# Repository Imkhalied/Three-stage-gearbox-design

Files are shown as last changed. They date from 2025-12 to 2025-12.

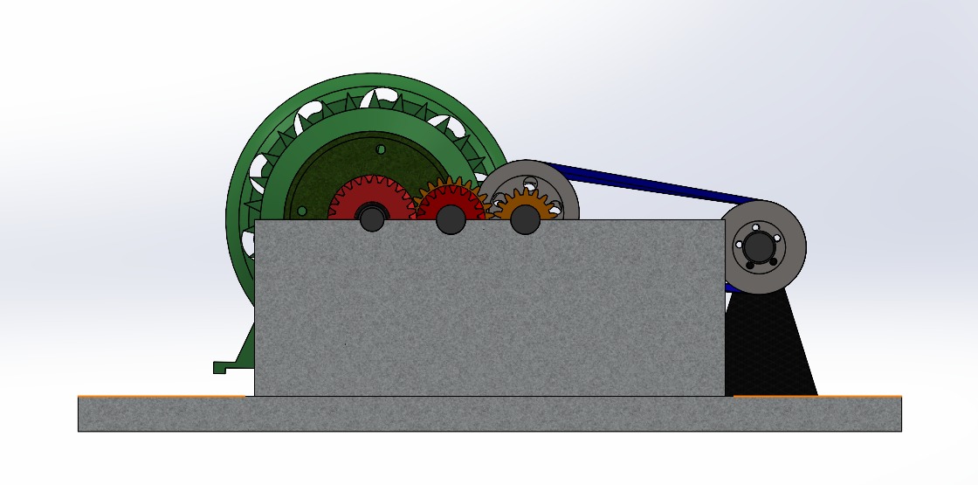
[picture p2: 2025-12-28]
Images/final_assembly_Sideview.jpeg

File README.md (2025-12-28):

# Three-Stage Gearbox Design

## Project Overview
Complete mechanical design of a three-stage gearbox starting from
analytical calculations to full CAD modeling and assembly.

## Project Contents
- Gear ratio and strength calculations
- Shaft,Bearing,Coupling,Gears,Pulley and key design
- Complete CAD parts and assemblies
- Engineering drawings

## Tools Used
- SolidWorks
- Hand Calculations / PDF Documentation

## Supervision
Dr. Mohamed Abdelmotaleb

## Author
Khaled Diaa – Mechatronics Engineering Student

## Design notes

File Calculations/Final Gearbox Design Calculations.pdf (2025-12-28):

1 | P a g e

# MSA

## October University for Modern Science & Arts

## Faculty of Engineering

## Department of Mechatronics Systems Engineering

## Machine Design (MSE243)

# Designing a Speed Increaser Gearbox

### Prepared By

## Khaled Diaa Eldin: 247181

## Joudy Ahmed: 245133

## Ali Abdelelah: 244093

## Seifeldin Eslam: 249437

## Muath Salaheldin: 240019

## Mina Nagy Louis: 248867

## Supervised By

## Dr. Mohamed Abdel Mottaleb

Fall 2025

2 | P a g e

# Table of Contents

# Design Requirements and Specifications

### The project task is to design a 3-stage of step-up gearbox comprised of a

### total of 4 shafts, 2 mating spur gears, 2 mating helical gears, and 2 connected

### belt pulleys. The specific parameters to operate on are:

### ❖ Input Power: 3.5 HP = 2.611 kW

### ❖ Input Speed: 750 rpm

### ❖ Output Speed: 1600 rpm

### ❖ Number of Stages: 3

### ❖ First Stage: Helical Gear

### ❖ Second Stage: Spur Gear

### ❖ Third Stage: Belt

3 | P a g e

# Design Calculations: Gears

## 3.1 Helical Gears

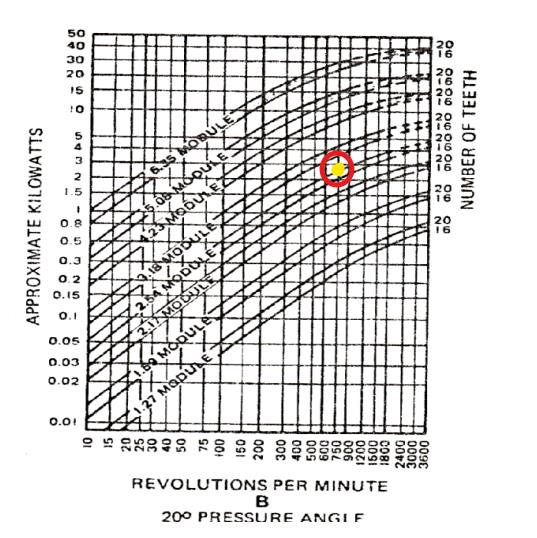
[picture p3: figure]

### ❖ Input Speed: 750 rpm

### ❖ Output Speed: 970 rpm

### ❖ Reduction Ratio: 1.27

### ❖ Pt = π ∗ m =8.63

### ❖ Pressure angle α = assume 20

❖ Px =

Pt
tan α

### = (8.63/tan 20) = 23.71

### ❖ F = 2Px m ≈ 59.275 mm

### ❖ Fa = wt

### tan β

### ❖ Helix angle β =assume 20

### ❖ N1 = 18 teeth

### ❖ m=2.54→Choose2.75(Next

### choice)

### ❖ d1 = N1*m = 18*2.75 = 49.5 mm

### ❖ N2 = N1*RR = 18*1.29≈24 teeth

### ❖ d2 = N2*m = 24*2.75 = 66 mm

## Safety Checks:

### 1. Bending Stress:

wt =

Power
Velocity =

2611
(

π∗D∗N
60

)

=

2611
(

π∗0.0495∗750
60

)

= 1340 N

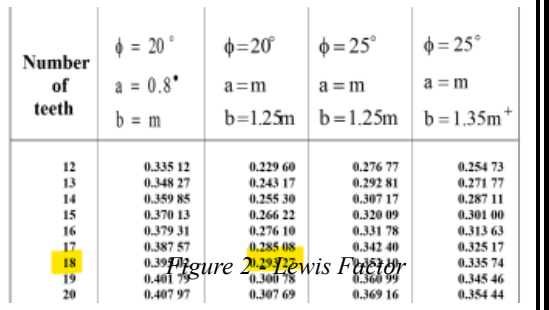
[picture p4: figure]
Figure 2 - Lewis Factor

Kv =

6
6 + V

= 0.7556 , Y = 0.29327

σ =

wt
F ∗ Kv ∗ m ∗ Y

Figure 1 - Module Table

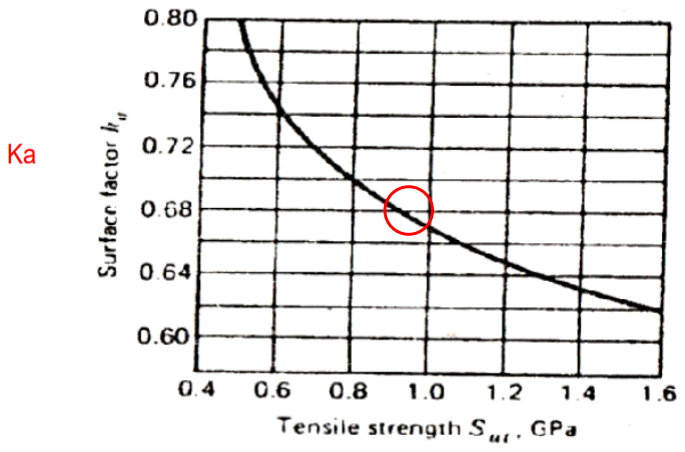
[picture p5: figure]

4 | P a g e

σ =

1340
0.059.275 ∗ 0.7556 ∗ 2.75 ∗ 0.29327 = 37.097MPa

σdesign = F. S ∗ σ = 2 ∗ 37.097 = 74.19 MPa

Cℎoose 1095 As rolled ; σy = 572.3 MPa , HB = 293

### 2. Bending Fatigue:

### Se = Ka KbKcKdKeKfSe

′

Figure 3 - Ka Table

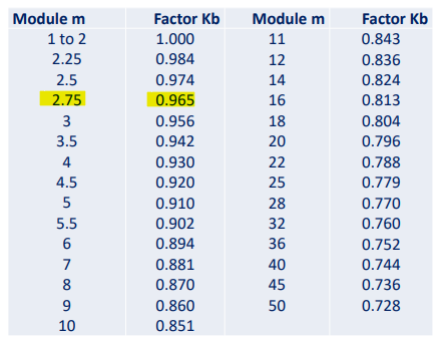
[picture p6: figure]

Figure 4 - Kb Table

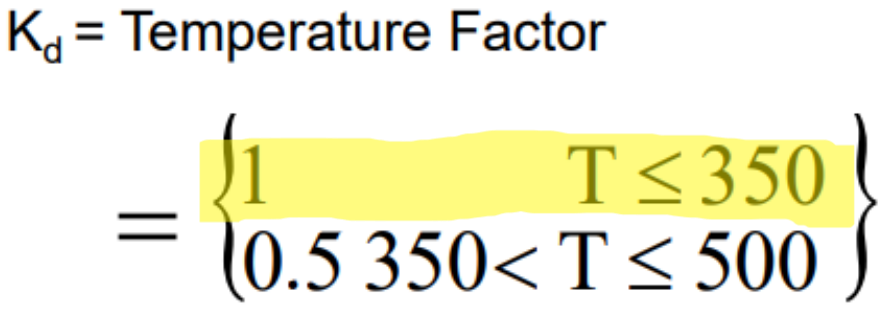
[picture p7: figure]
Figure 5 - Kc Table

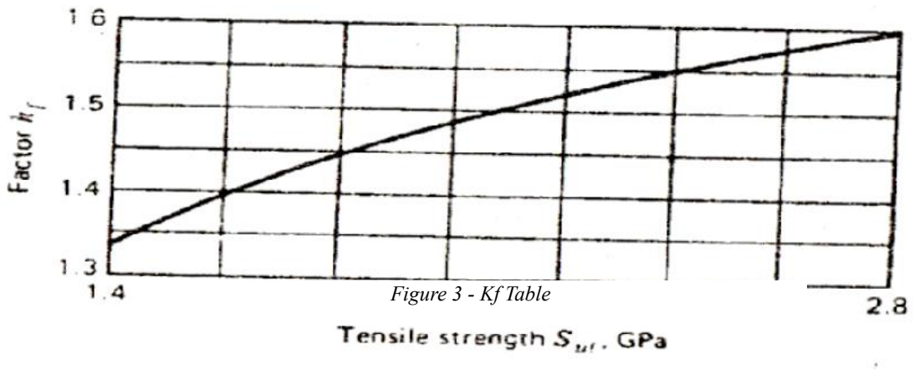
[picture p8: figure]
Figure 3 - Kf Table

5 | P a g e

## Ke = Modified factor for stress concentration = 1

Ka = 0.68

Kb = 0.956

Kc = 0.725

Kd = 1

Ke = 1

Kf = 1

Se

′ =

σult
2

=

955.3
2

### = 482.65MPa

### Se = 229.61MPa

σa =

1340
0.059 ∗ 0.7556 ∗ 2.75 ∗ 0.33214 = 32.755MPa

nG =

Se
σa

=

2291.61
32.755 = 7

n =

nG
KoKm

=

7
1 ∗ 1.3

= 4.3 > 1

## Safe

Figure 4 - Geometry Factor

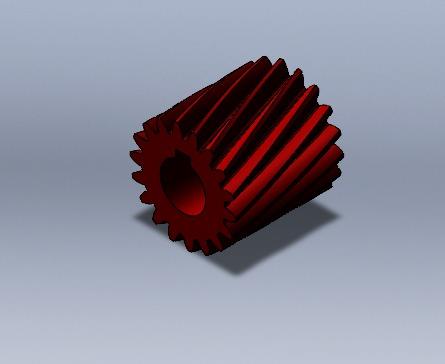
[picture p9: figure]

6 | P a g e

### 3. Surface Durability:

### Sc = 2.76 ∗ HB − 70 = 2.76 ∗ 293 − 70 = 738.68 MPa

SH =

### CLCH CTCR

∗ Sc =

1 ∗ 1
1 ∗ 1.25

### ∗ 738.68 = 590.944 MPa

### σH = 590.944 MPa = Cp√

wtp

### Cv ∗ F ∗ d ∗ I

I =

### cos ∅ sin ∅

2

∗

m
m + 1

= 0.1178

σH = 191√

wtp
0.7556 ∗ 0.059 ∗ 0.0495 ∗ 0.1178

### wtp = 2492 N

nG =

wtp
wt

=

2492
1340 = 1.86

n =

nG

### cocm

=

1.86
1 ∗ 1.3

= 1.14 > 1

## Safe

Figure 7 - Driven Helical Gear Figure 6 - Pinion Helical Gear

7 | P a g e

## 3.2 Spur Gears

### ❖ Input Speed: 750 rpm ❖ Output Speed: 970 rpm ❖ Reduction Ratio: 1.3 ❖ N1 = 18 teeth

❖ m = 2.75

### ❖ d1 = N1*m = 18*2.75 = 49.5 mm ❖ N2 = N1*RR = 18*1.3≈ 24 teeth ❖ d2 = N2*m = 24*2.75 = 66 mm

### ❖ F = 4 ∗ π ∗ m = 34.55mm ≈ 35mm

## Safety Checks:

1- Bending Stress:

wt =

### Power Velocity =

2611
(

π∗D∗N
60

)

=

2611
(

π∗0.0495∗970
60

)

= 1028 N

Kv =

6
6 + V

= 0.7 , Y = 0.29327

σ =

wt

### F ∗ Kv ∗ m ∗ Y

=

1038.55

### 0.035 ∗ 0.7 ∗ 2.75 ∗ 0.29327 = 52 MPa

### σdesign = F. S ∗ σ = 2 ∗ 52 = 104 MPa < σy

## Safe

8 | P a g e

2- Bending Fatigue

### Se = Ka KbKcKdKeKfSe

′

Ka = 0.8

Kb = 0.965

Kc = 0.725

Kd = 1

Ke = 1

Kf = 1

Se

′ =

σult
2

=

424
2

### = 212 MPa

### Se = 118.65 MPa

σa =

wt

### F ∗ Kv ∗ m ∗ J

=

1038.55

### 0.035 ∗ 0.88 ∗ 2.75 ∗ 0.33814 = 36.54 MPa

nG =

Se
σa

=

118.65
36.54 = 3.255

n =

nG

### KoKm

=

3.255
1 ∗ 1.3

= 2.5 > 1

## Safe

9 | P a g e

3- Surface Durability:

### Sc = 263.96 MPa

SH =

### CLCH CTCR

∗ Sc =

1 ∗ 1
1 ∗ 1.3

### ∗ 263.96 = 343.148 MPa

### σH = Cp√

wt

### Cv ∗ F ∗ d ∗ I

;I =

### cos ∅ sin ∅

2

∗

m
m + 1

= 0.1175

σH = 191√
584

### 0.88 ∗ 0.035 ∗ 0.05 ∗ 0.1175 = 343.148 MPa

nG =

SH
σH

=

584
1038 = 0.568

n =

nG

### cocm

=

0.568
1 ∗ 1.3

= 0.437 > 1

## Not Safe

Cℎanged material to 1050 Normalized ;

HB = 201

### Sc = 484.76 MPa

SH =

### CLCH CTCR

∗ Sc =

1 ∗ 1
1 ∗ 1.3

### ∗ 484.76 = 630.18 MPa

### wtp = 1.915 N

n =

nG

### cocm

=

1.915
1 ∗ 1.3

= 1.473 > 1

## Safe

10 | P a g e

Figure 6 - Pinion Spur Gear

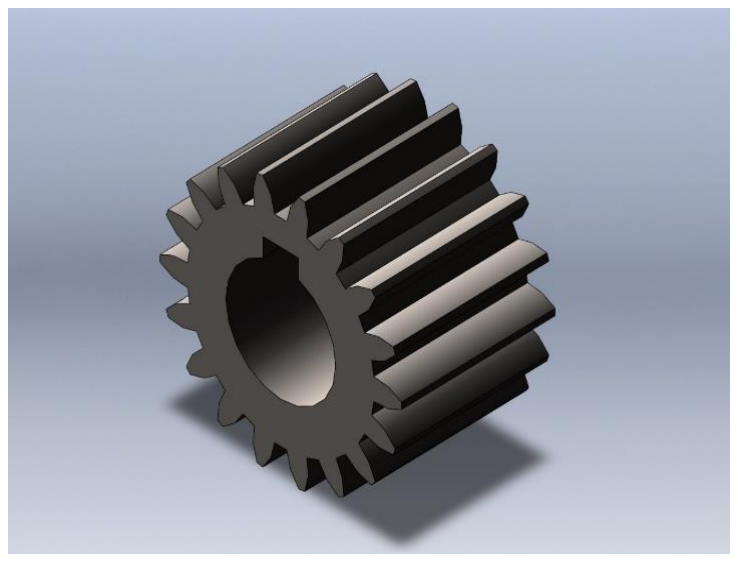
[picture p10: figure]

Figure 5 - Driven Spur Gear

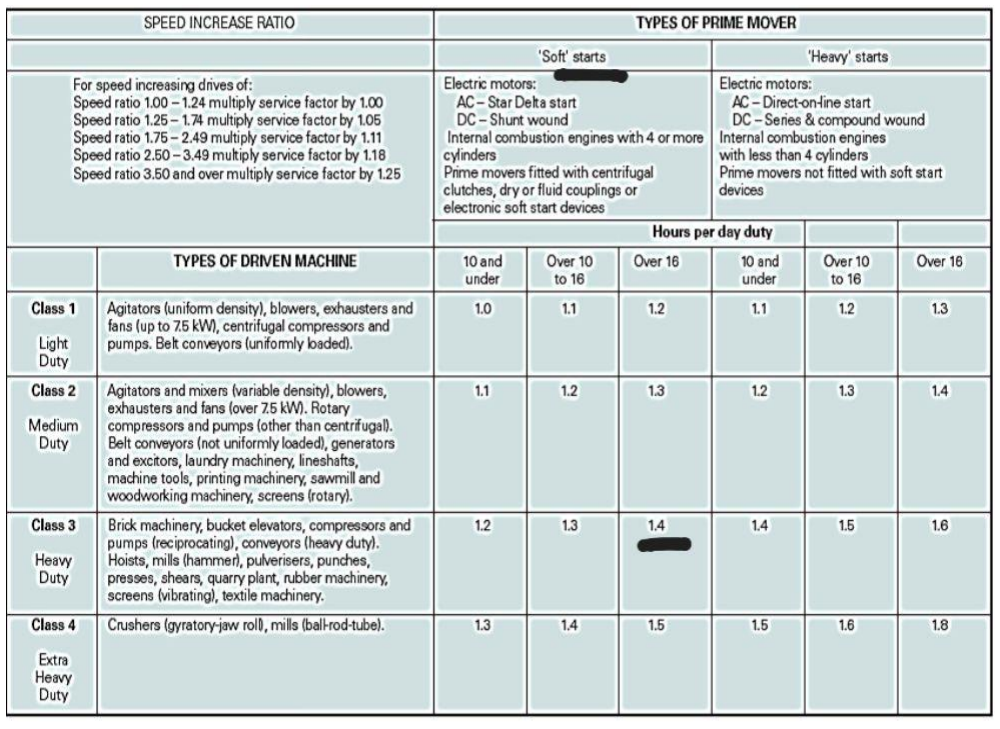
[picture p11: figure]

11 | P a g e

# Pulley and Belt Design

### Input Power= 3.5 Hp = 2.611 KW

### ❖ Input Speed = 1260 rpm

### ❖ Reduction ratio= 1.27

(a) Speed Ratio

Speed ratio=0.02

(b) Service Factor

From Table 3 the service factor is 1.4 .as we use an internal combustion engine with 4

cylinders

➔ Class 2→ Agitators and Mixers → (over 16) hours

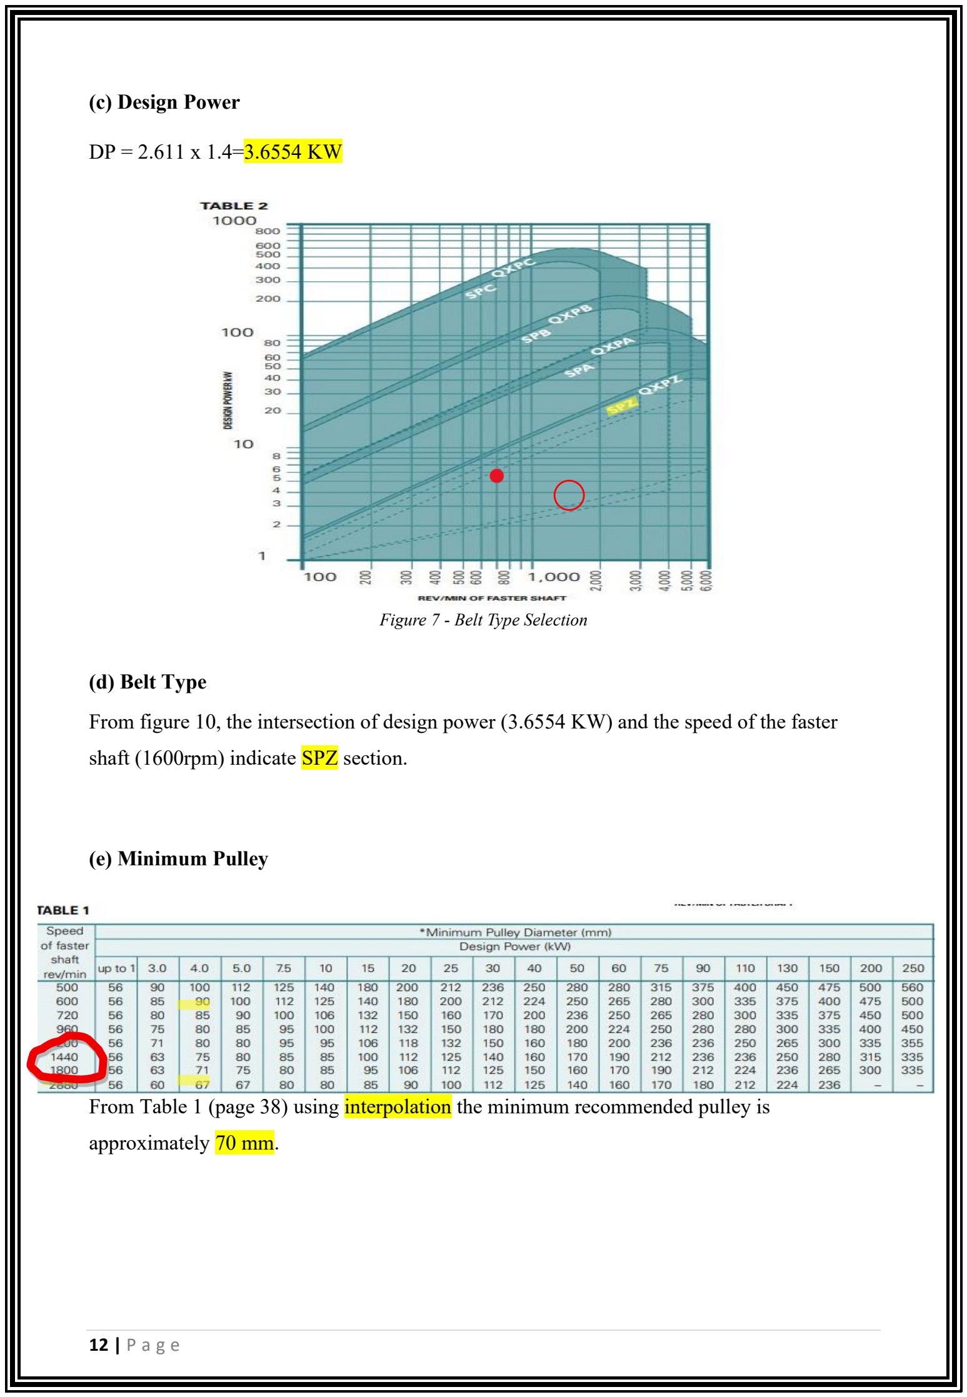
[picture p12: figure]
(c) Design Power; (d) Belt Type; shaft (1600rpm) indicate SPZ section.; (e) Minimum Pulley; approximately 70 mm.; Figure 7 - Belt Type Selection

From figure 10, the intersection of design power (3.6554 KW) and the speed of the faster

From Table 1 (page 38) using interpolation the minimum recommended pulley is

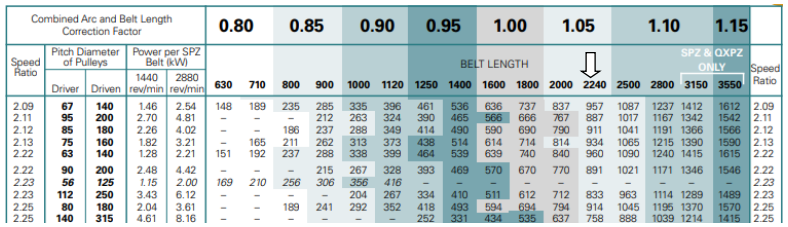
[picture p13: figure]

13 | P a g e
(f) Pulley Pitch Diameters

By referring to the center distance tables relating to SPZ section belts on page 47 at reduction

ratio 1.293, the selection is a driving pulley of 70 mm pitch diameter and a driven pulley of

71 mm and 90 mm pitch diameter.

(g) Belt Length, Centre Distance and Correction Factor

Reading across the table, the nearest center distance to the 873 mm required is 994 mm. The

belt length at the head of the column is 2240 mm. By following the shading of the color to the

top of the table, a correction factor of 1.05 is noted.

(h)Rated Power per Belt

From the power rating table (pages 54 & 57), the rated power is 1.57kW(Using interpolation)

for Power Plus SPZ(power per belt).

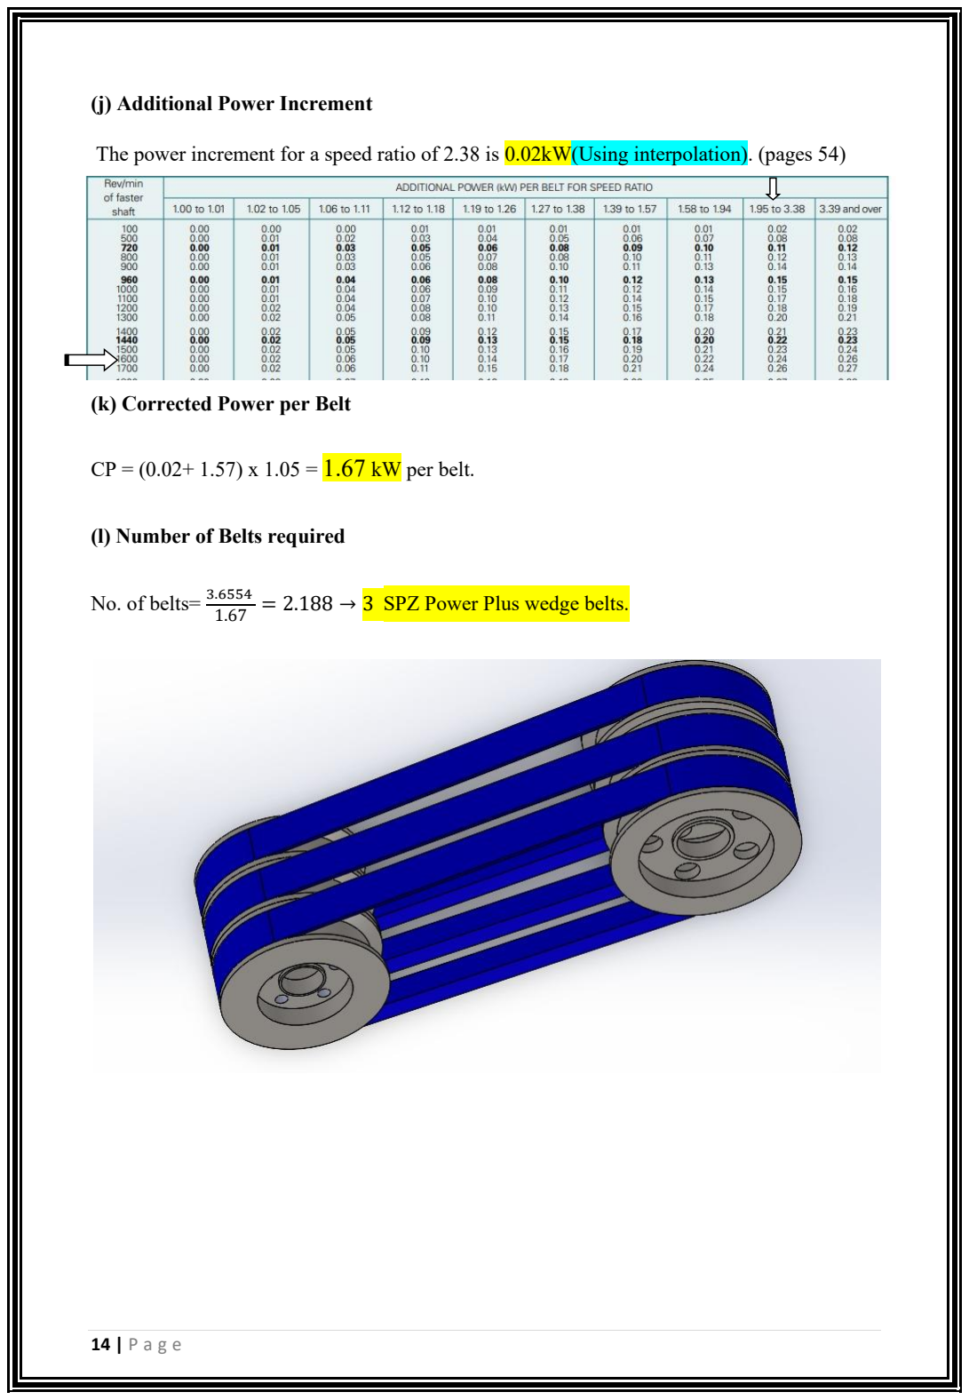
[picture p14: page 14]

14 | P a g e
(j) Additional Power Increment

The power increment for a speed ratio of 2.38 is 0.02kW(Using interpolation). (pages 54)

(k) Corrected Power per Belt

CP = (0.02+ 1.57) x 1.05 = 1.67 kW per belt.

(l) Number of Belts required

No. of belts=

3.6554
1.67 = 2.188 → 3 SPZ Power Plus wedge belts.

15 | P a g e

### Therefore, the results of the belt design are the following:

### ❖ Input Speed: 1260 rpm

### ❖ Output Speed: 1600 rpm

### ❖ Reduction Ratio: 1.27

### ❖ Power: 2611 W

### ❖ Service Factor = 1.4

### ❖ Design Power =

2.611*1.4= 3.6554 kW

### ❖ Belt Type: SPZ

### ❖ Minimum Pulley

### Diameter = 70 mm

### ❖ Pulley Diameters = 71 &90 mm

### ❖ Center Distance = 873-994 mm

### ❖ Belt Length = 2000-2240 mm

### ❖ Correction Factor = 1.05

### ❖ Rated Power = 1.57 kW

### ❖ Additional Power

### Increment = 0.02 kW per belt

### ❖ Power Per Belt =

1.05(1.57+0.02) =

### 1.67 kW/belt

### Number of Belts =

### Design Power Power Per Belt =

3.6554

### 1.67 = 2.188 ≈ 3 belts

16 | P a g e

# Coupling Design

1. Input Power= 3.5 HP
2. Input Speed = 750 rpm

1- Select a type of coupling

Choose a cast iron rigid coupling→ Cast iron

2- Selecting a proper material with a yield strength from the table material

From table of (AISI) 1030 asrolled with yield strength (σ yield)344.7 MPa, Factor of safety= 6

Permissible shear stress for bolts, shaft, and key material: 0.5 SY
F.S

=

0.5∗344.7
6

=28.725MPa

Crushing stress for bolt and key material:
SY
F.S

=

344.7
6

=57.45 MPa

Permissible shear stress for cast iron: 8 MPa(assume )

3- Get Torque from power

Power= 3.5Hp = 2611 W = 2.611 KW

Power= Tw

T= input Power
input speed

=

P
2πN
60

=

2.611∗ 10³
2π∗750
60

= 33.25 N.m

17 | P a g e

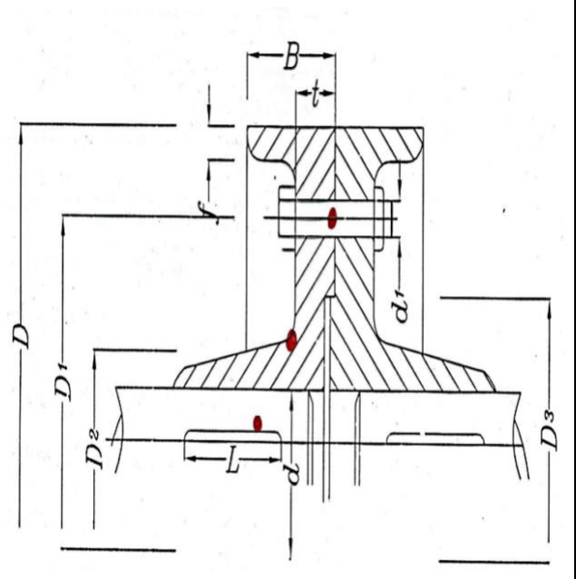
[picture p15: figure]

5- Coupling dimensions proportions (see Figure) for

the nomenclature

1. No. of bolts =n = 0.02d+3= 0.02*20+3= 3.4≈

4 bolts (even number for symmetry)

2. d1(diameter of bolts)=

0.5d
√n

=

0.5∗20
√4

=5mm ≈M6

3. D1(diameter of pitch circle)= 4d = 4*20=80mm
4. D2(outer diameter of hub) = 2d= 2*20=40 mm
5. L1(length of hub) = 1.5d= 1.5*20= 30 mm
6. D(outside diameter of flange)= 5d= 5*20= 100 mm

(Diameter of Coupling)

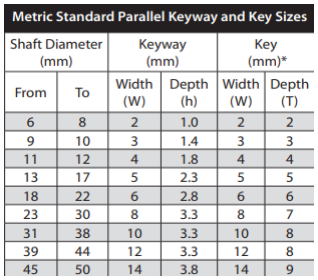
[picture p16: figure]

7. t= 1.2 d1= 1.2*6=7.2mm
8. f= 6 for Cast Iron

From table of Metric standard keyway and key size at

d= 20 mm

Keyway: W= 6mm, h= 2.8 mm

Key: W= 6 mm, h= 6 mm

6- the following checks should be doneafter the assumptions of the coupling dimensions

1- Direct shear check on bolts:

Fbolt =

2T
nD1

=

2∗33,25
4∗80∗10⁻³ = 207,8 N

τbolt =

F
π
4

d1

2 =

207,8
π
4

∗6

2 = 7,36 MPa <28.7 MPa

∴ It’s SAFE

2- Bearing pressure on bolts:

σb =

Fb
d1∗t

=

207.8
6∗7.2

= 4.81 MPa

σb =

Sb
F. S

→ 4.81 <

57.45x10⁶
6

= 9.575 MPa

18 | P a g e

∴ It’s SAFE

3- Shear of the flange at hub:

τ =

2T
πD2

2
∗t

=

2∗33.25
π∗40²∗7.2

= 1.84 MPa< 8 MPa

∴ It’s SAFE

4-Shear Stresson Key

τkey =

2T
d∗w∗L

=

2∗33,25
20∗6∗30

= 18,4 MPa < 28,725 MPa

∴ It’s SAFE

36.9 MPa < 57.45 MPa

∴ It’s SAFE

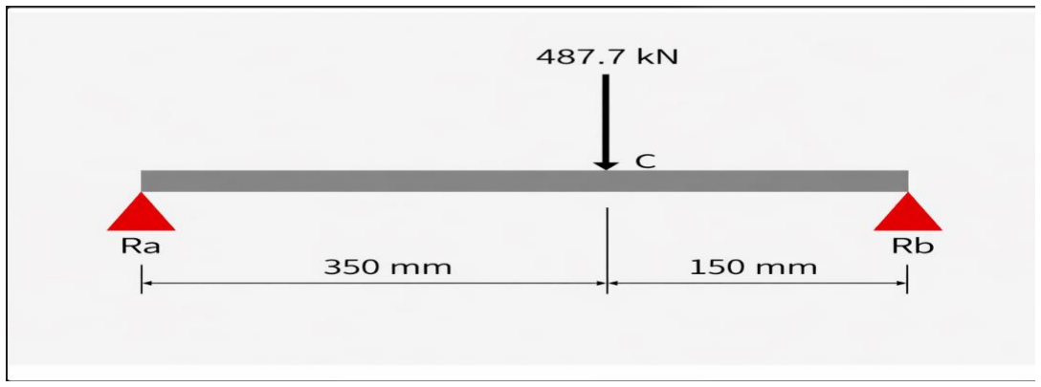
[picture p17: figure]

19 | P a g e

# Shafts Design

1

## st Shaft: (Helical)

Power = 2.611 kW

(X-Y Plane)

### ❖ Tangent force wt= 1340 N

### ❖ Axial force Fa = wt

### tan β= 487.7 N

### ❖ Normal force FN = wt

### tan α = 487.7 N

### ❖ RA=146.31 N ❖ RB=341.4 N

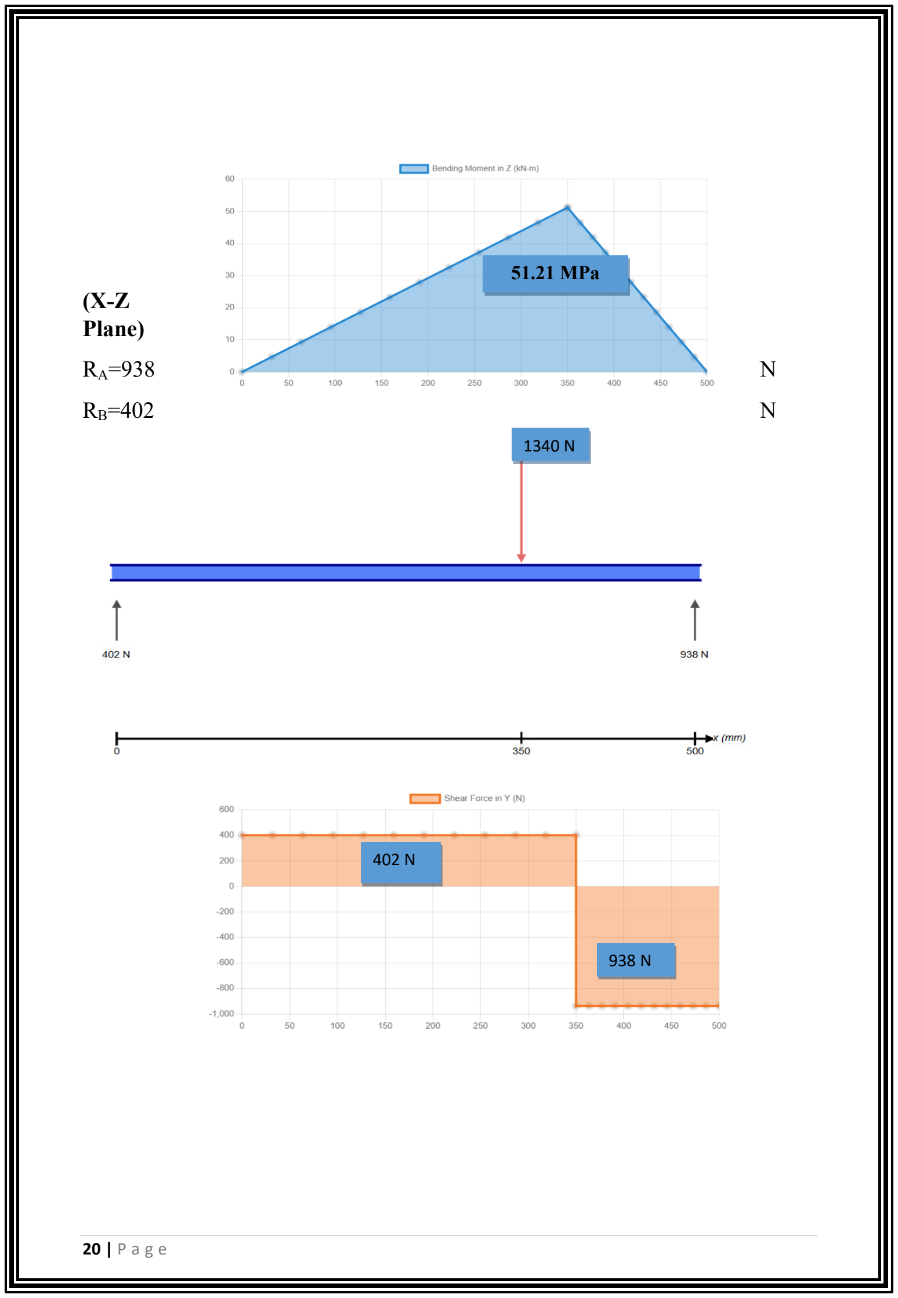
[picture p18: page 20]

20 | P a g e

(X-Z
Plane)
RA=938 | N
RB=402 | N

### 51.21 MPa

1340 N

402 N

938 N

21 | P a g e

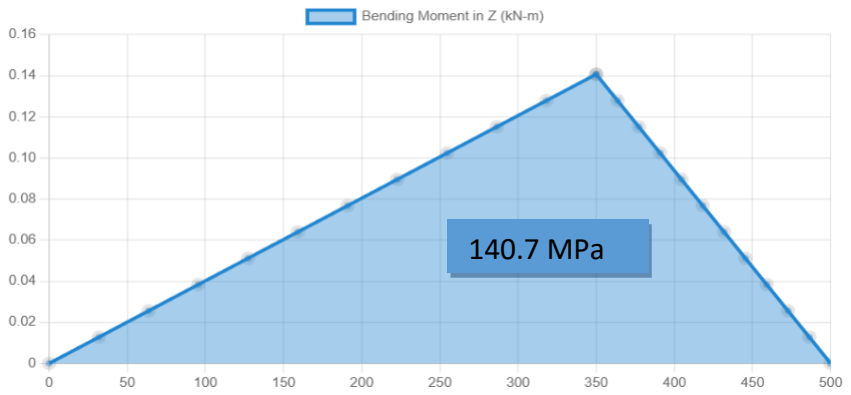
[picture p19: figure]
140.7 MPa

### Momentmax = √140.7 2 + 51.21² + 12.071² = 150.21 Nm

### Torquemax= 33.24Nm

### Km = Kt = 1.5

d

3 =

32 ∗ FS

### π ∗ Sy

### ∗ √(Kt ∗ Torquemax) 2 + (Km ∗ Momentmax)

2

### d = 18.3mm→ Choose 20mm

## 2nd Shaft: (Spur + Helical)

22 | P a g e

Power =2.611 kW

(X-Y Plane)

### RA=78.181 N

### RB=191.72 N

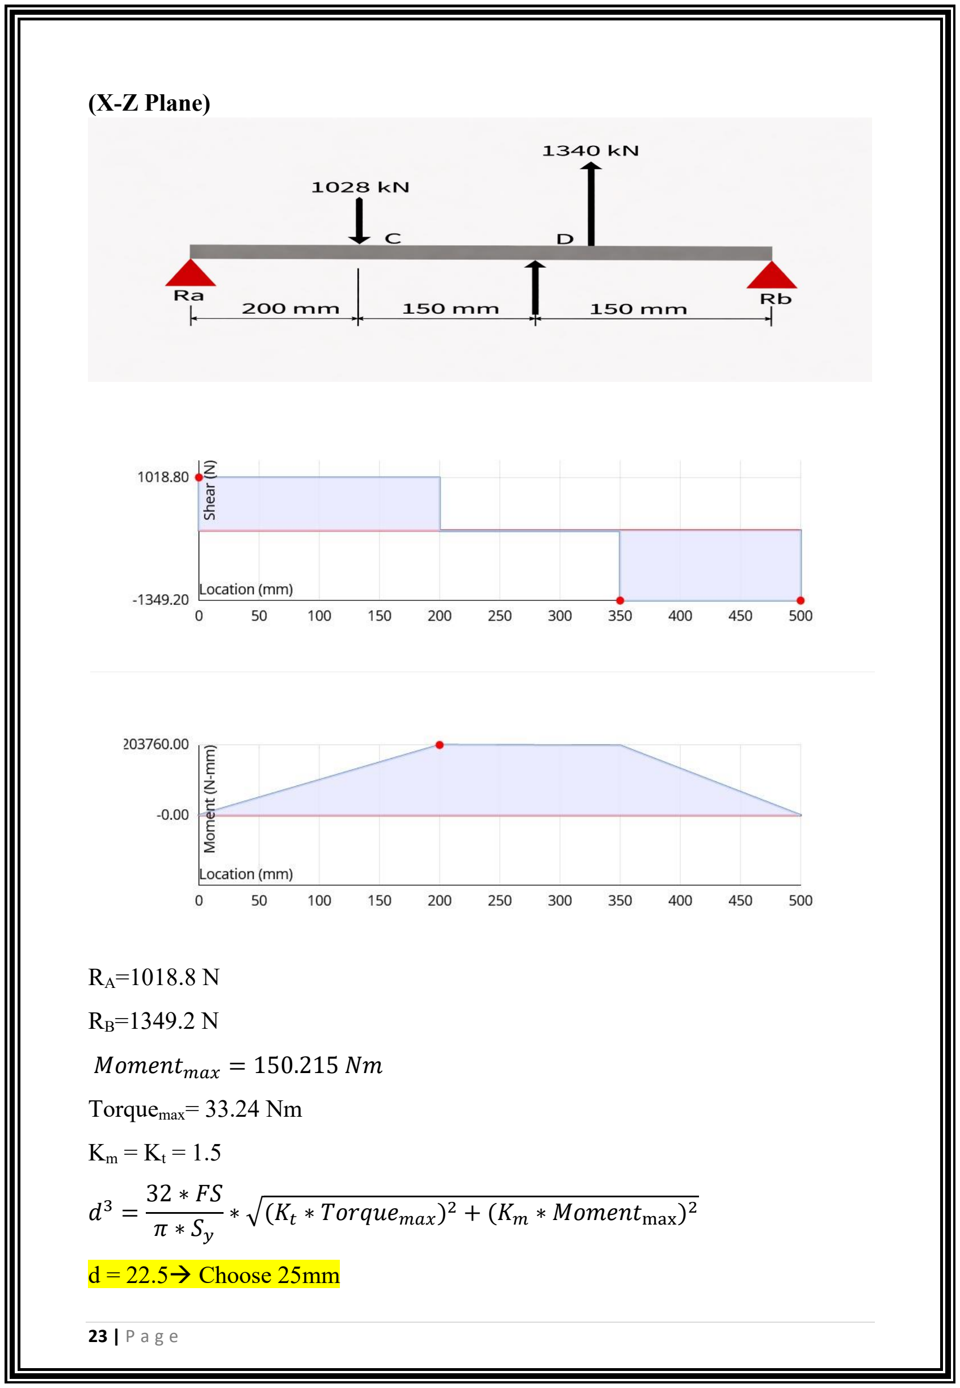
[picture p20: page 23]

23 | P a g e

(X-Z Plane)

### RA=1018.8 N

### RB=1349.2 N

### Momentmax = 150.215 Nm

### Torquemax= 33.24 Nm

### Km = Kt = 1.5

d

3 =

32 ∗ FS

### π ∗ Sy

### ∗ √(Kt ∗ Torquemax) 2 + (Km ∗ Momentmax)

2

### d = 22.5→ Choose 25mm

24 | P a g e

## 3rd Shaft: (Helical + Belt Pulley)

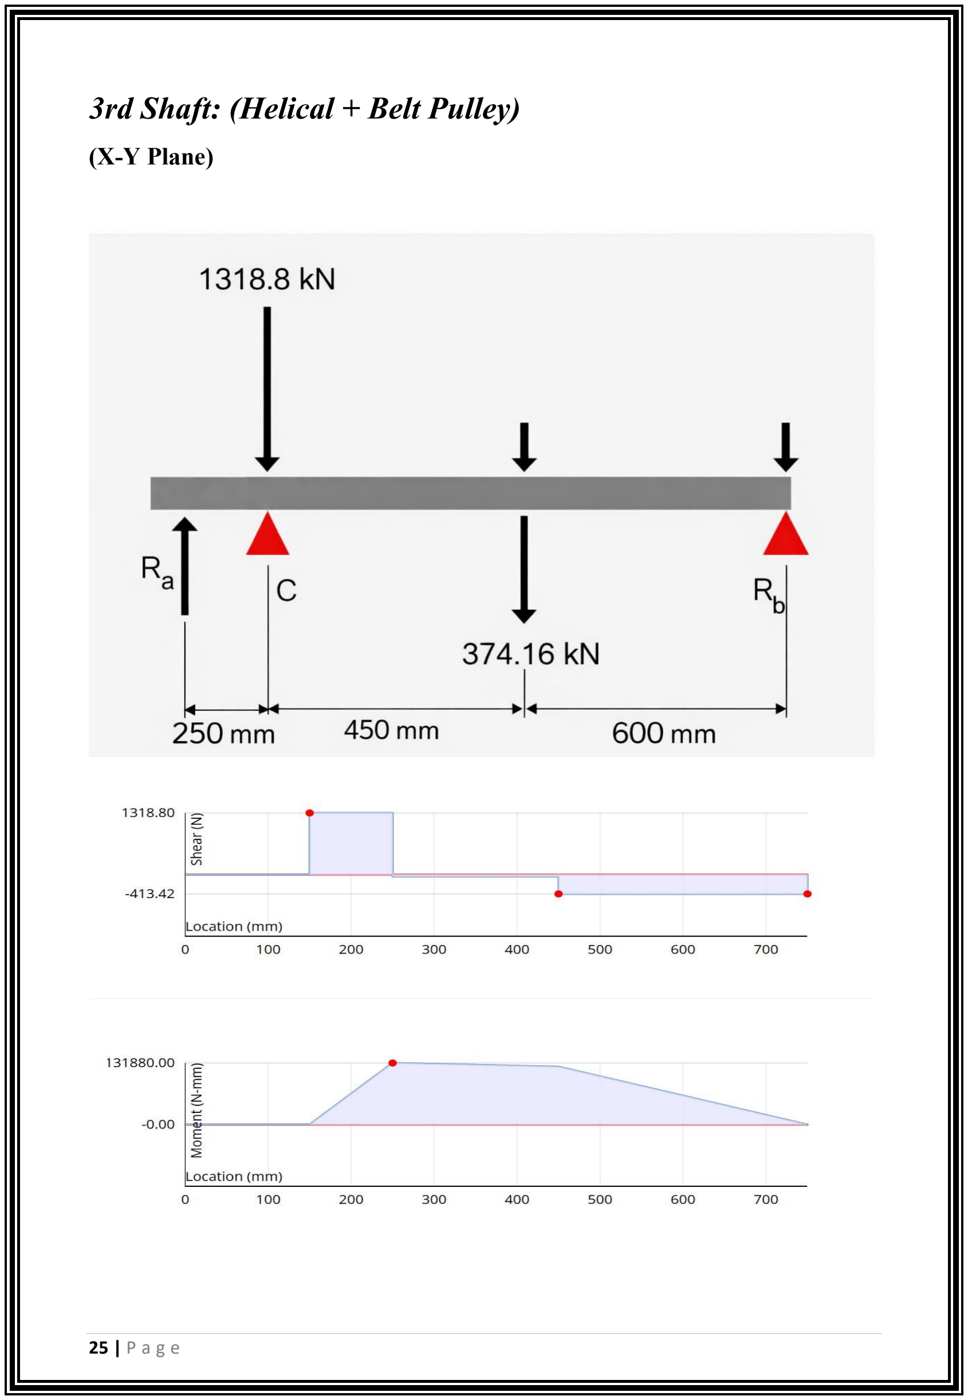
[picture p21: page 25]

25 | P a g e

(X-Y Plane)

26 | P a g e

### RA=1358.064 N

### RB=413.405 N

(X-Z Plane)

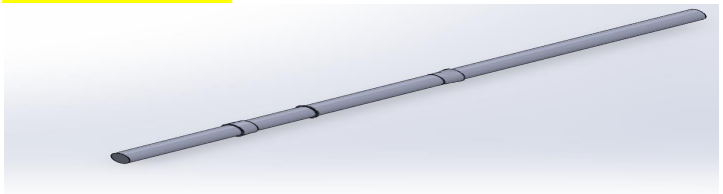
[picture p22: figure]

27 | P a g e

### RA=616.8 N

### RB=411.2 N

### Momentmax = 180.58 Nm

### Torquemax= 19.78 Nm

### Km = Kt = 1.5

d

3 =

32 ∗ FS

### π ∗ Sy

### ∗ √(Kt ∗ Torquemax) 2 + (Km ∗ Momentmax)

2

### d = 21.5→ Choose 25mm

## 4th Shaft: (Belt Pulley)

28 | P a g e

(X-Y Plane)

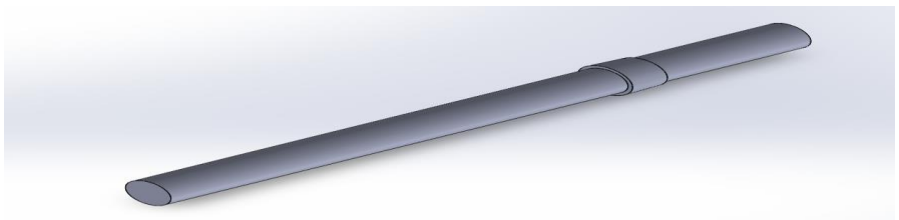
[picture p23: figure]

29 | P a g e

### RA=955.17 N

### RB=716.378 N

### Momentmax = 143,27 Nm

### Torquemax= 1671.549 Nm

### Km = Kt = 1.5

d

3 =

32 ∗ FS

### π ∗ Sy

### ∗ √(Kt ∗ Torquemax) 2 + (Km ∗ Momentmax)

2

### d = 20→ Choose 25mm

30 | P a g e

# Bearings Design

1

## st Shaft:

Choose ball bearing

1- Select bearing type from the data sheet table, then get C, Co

At diameter 20 mm

RPm = 750

Fr = 998.95 KN

Fa = 773.65 KN

From table bearing type: Single row deep groove ball bearings61804-2RS1

C= 4.03 kN, Co= 2.32 kN

ΣFy ∣B= √(341.4)
2 + (938)

2 = 998.095 N
FR = 998.95 N
Fa = FRtan (20∘

) = 1340tan (20∘
) = 773.65 N

2- Get P

⸪P = 0.56Fr + yFa | @ y =

0.44
e

⸫e = 0.5 (

Fa
Co

)

0.225
= 0.39

⸪ IfFa
Fr

≤ e then P = Fr

If Fa
Fr

≥ e then P = 0.56Fr + yFa

31 | P a g e

⸫

Fa
Fr

≥ e

0.774 ≥ 0.39

⸪P = 0.56 ⋅ 998.95 + y ⋅ 773.652 @ y =

0.44
e

= 1.128

P = 1432.294 N

3-Assume life, for gear box L=12,000 working hr

4- Calculate L=

[

C
P

]

a
X106

N 60

to get C where a=3 (ball bearing)

L=

[

C
P

]

a
X10⁶

N∗ 60

; 12,000=

[

C
1432.294 ]

3
X10⁶

∗ 60
From equation above, get C = 11.663 kN>4.03 kN

IT’S NOT SAFE

⸫ Change material to 6204

C = 13.55 kNCo = 6.55 kN

⸪e = 1.463y =

0.44
e

= 0.3

- P = Fr = 998.65 N

•

[

C
P

]

a
X106

N 60

C` = 8. 132 kN

- C`<C 8.132<13.55

⸫ IT`S SAFE

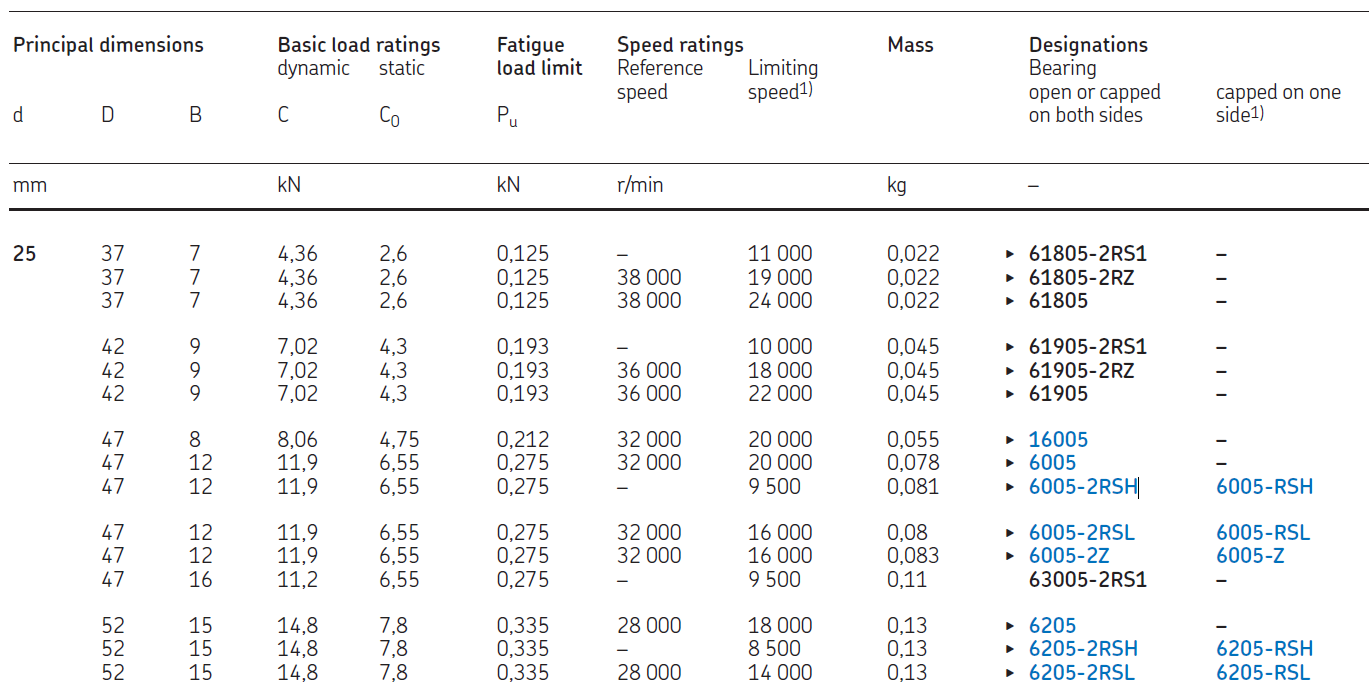
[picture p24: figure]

32 | P a g e

2

## ndShaft:

Given data:

dsℎaft = 25 mm

N = 970 rpm

Fa = 773,65 N

Fr = 1362 N

Choose ball bearing

1- Select bearing type from the data sheet table, then get C, Co

At diameter 25 mm

From table bearing type: 6205-2RSH

C= 14.8kN, Co= 7.8 kN

FR ∣B= √(1352.2)
2 + (191.78)

2 = 1362 N
Fa = FRtan (30∘
)
Fa = 1340tan (30∘
) = 773.65 N

2-Assume life, for gear box L=12,000 working hr

33 | P a g e

3-Get P

e = 0.5(

Fa
Co

)

0.225 = 0.5(

773,65
7800 )

0.225 = 0.2973

Fa
Fr

=

773,65
1362 = 0.568; > e,tℎen P = 0.56Fr + (

0.44
e

)Fa

P = 0.56 ∗ 1362 + (

0.44
0.2973) ∗ 773,65 = 1907.722 N

4- Calculate L=

[

C
P

]

a
X106

N∗ 60

to get C where a=3 (ball bearing)

L=

[

C
P

]

a
X10⁶

N ∗ 60

= 12,000=

[

C`
1907.722]

3
X10⁶

970∗ 60

From the equation above, get C`= 16.925 kN>14.8 kN

IT’S NOT SAFE

- Changing material to 6305 ETN9

C= 26 kN Co = 13.4 kN
e=0.2632 y =

0.44
e

= 1.6717

•p = 0.56 ∗ 1362 + 1.6717 ∗ 773.65= 2056.03 N

- C`=18.241 kN

⸫ C`< C

18.241<26

IT’S SAFE

34 | P a g e

3

## rdShaft:

Given data:

dsℎaft = 25mm

N = 1260 rpm

Fa = 0

Fr = 1491.51N

17.8 9.3

Choose ball bearing

1- Select bearing type from the data sheet table, then get C, Co

At 25 mm diameter

From table bearing type: Single row deep groove ball bearings6205 ETN9

C= 17.8 kN, Co= 9.3 kN

35 | P a g e

2-Assume life, for gear box L=12,000 working hr

3-Get P

P = Fr = 1491.5 N

4- Calculate L=

[

C
P

]

a
X106

N 60

to get C where a=3 (ball bearing)

L=

[

C
P

]

a
X10⁶

N∗ 60

= 12,000=

[

C`
1491.51]

3
X10⁶

1260∗ 60
From the equation above, get C`= 14.438kN<17.8 kN

IT’S SAFE

36 | P a g e

4

## thShaft:

Given data:

dsℎaft = 25 mm

N = 1600

Fa = 0

Fr = 955.17N

Choose ball bearing

1- Select bearing type from the data sheet table, then get C, Co

At 25 mm diameter

From table bearing type: Single row deep groove ball bearings6005-2RSH

C= 11.9 kN, Co= 6.55 kN

2-Assume life, for gear box L=12,000 working hr

3-Get P

⸪ Fa = 0

⸫ P=Fr= 955.17 N

4- Calculate L=

[

C
P

]

a
X106

N 60

to get C where a=3 (ball bearing)

L=

[

C
P

]

a
X10⁶

N 60

= 12,000=

[

C`
955.17]

3
X10⁶

300 ∗ 60
From the equation above, get C`= 10.013 kN<11.9 kN

IT’S SAFE

# Assembly Drawings (SolidWorks)

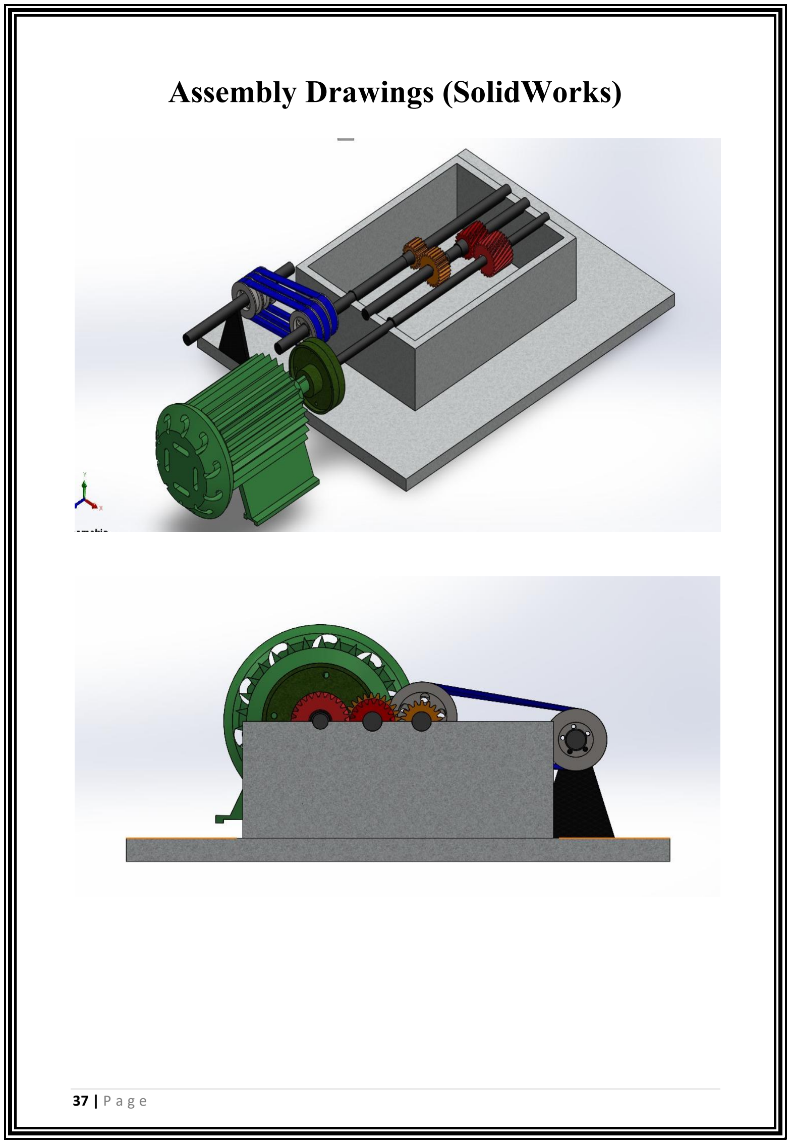
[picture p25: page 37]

37 | P a g e

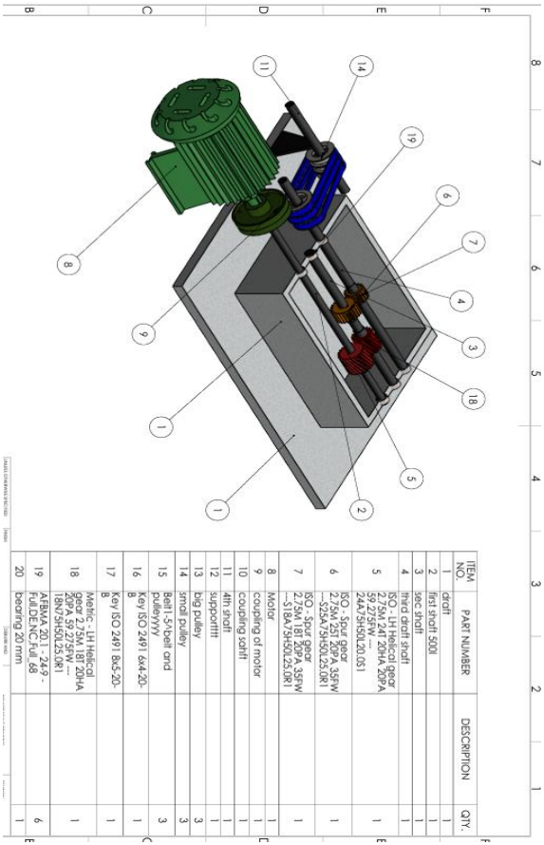
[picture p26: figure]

38 | P a g e

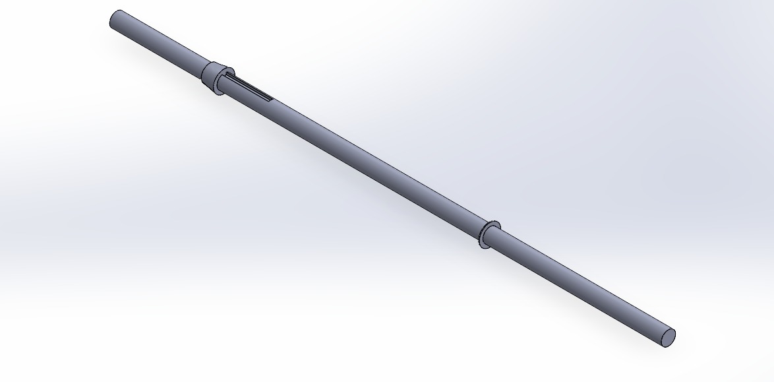
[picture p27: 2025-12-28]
Images/shaft_stage_1.jpeg

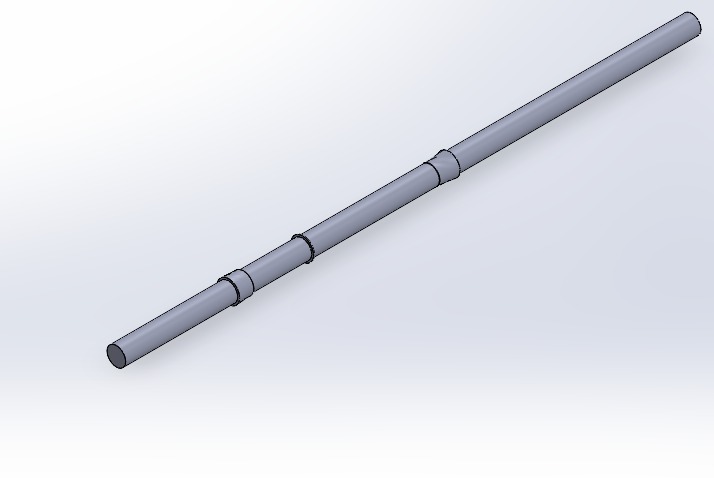
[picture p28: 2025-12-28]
Images/shaft_stage_3.jpeg

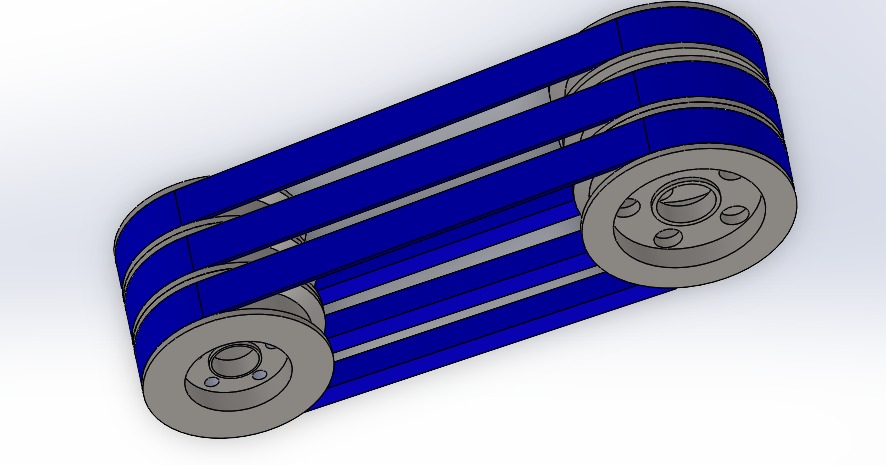
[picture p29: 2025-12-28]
Images/belt_pulley_transmission.jpeg

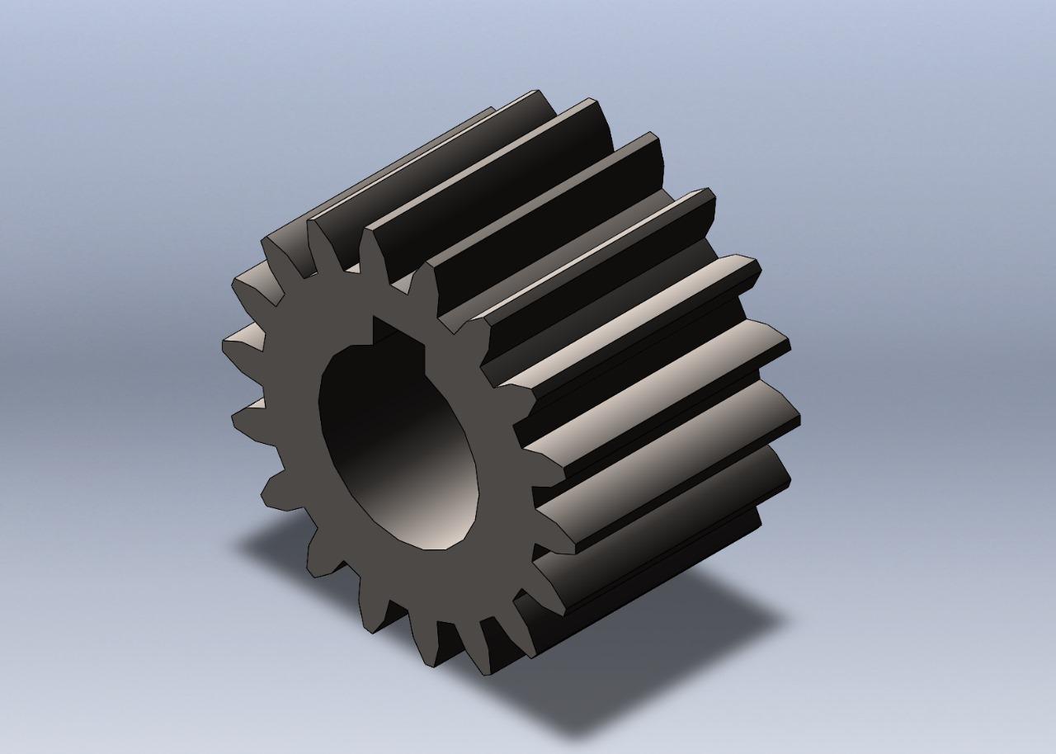
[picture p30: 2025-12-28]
Images/gear_stage_2_Spur_driven.jpeg

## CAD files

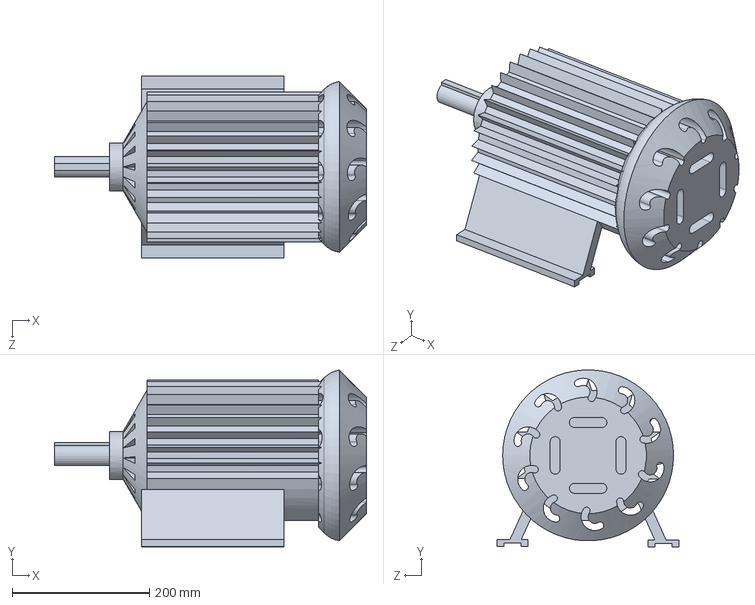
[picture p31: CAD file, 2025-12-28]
CAD/Assemblies/Motor.SLDPRT
454.6 x 257.8 x 264.7 mm

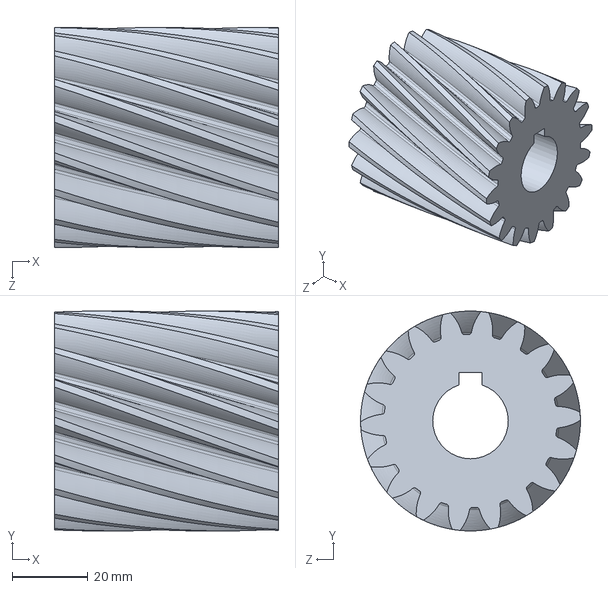
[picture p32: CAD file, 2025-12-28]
CAD/Parts/Gears/gear_stage_1_Helical_driven.SLDPRT
59.3 x 58.2 x 58.2 mm

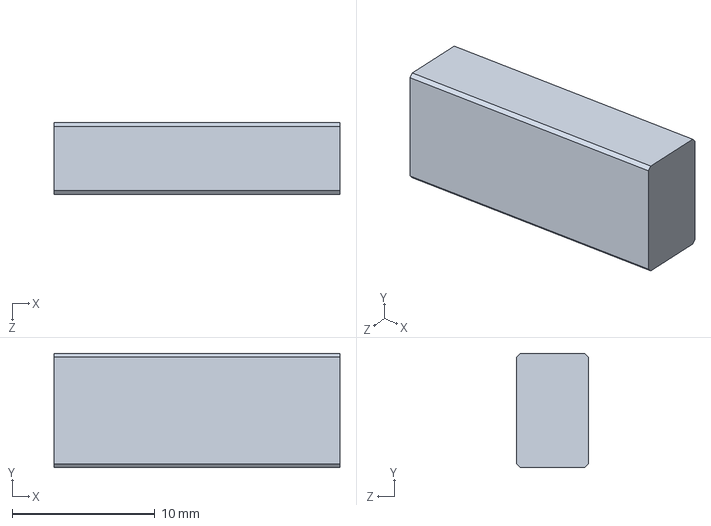
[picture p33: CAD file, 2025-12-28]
CAD/Parts/Key & Bearing/key_d25.SLDPRT
20.0 x 8.00 x 5.00 mm

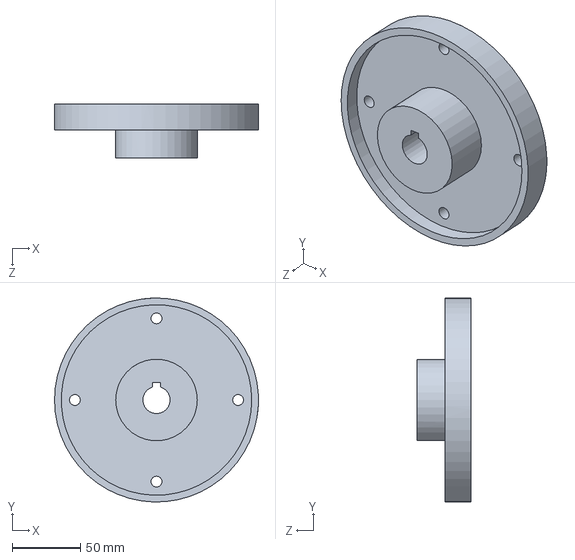
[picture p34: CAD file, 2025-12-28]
CAD/Parts/Power_Transmission/Coupling/Shaft_coupling.SLDPRT
150.0 x 149.9 x 39.6 mm

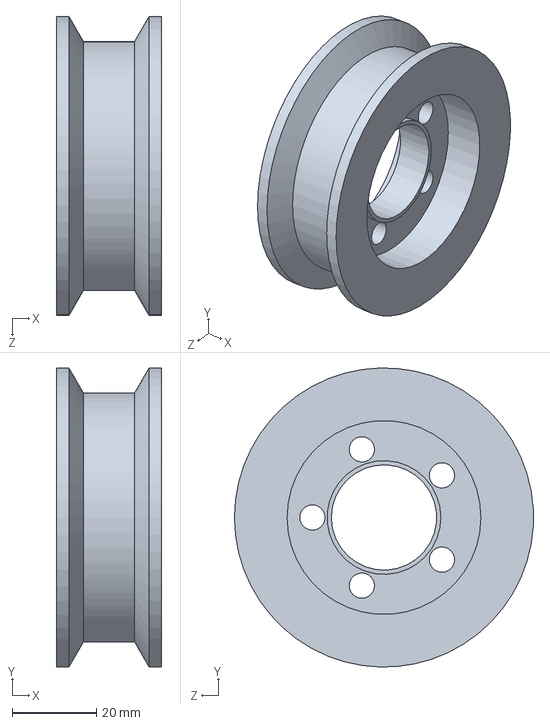
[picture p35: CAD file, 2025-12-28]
CAD/Parts/Power_Transmission/Pulley & Belt/pulley_small.SLDPRT
25.0 x 71.0 x 71.0 mm

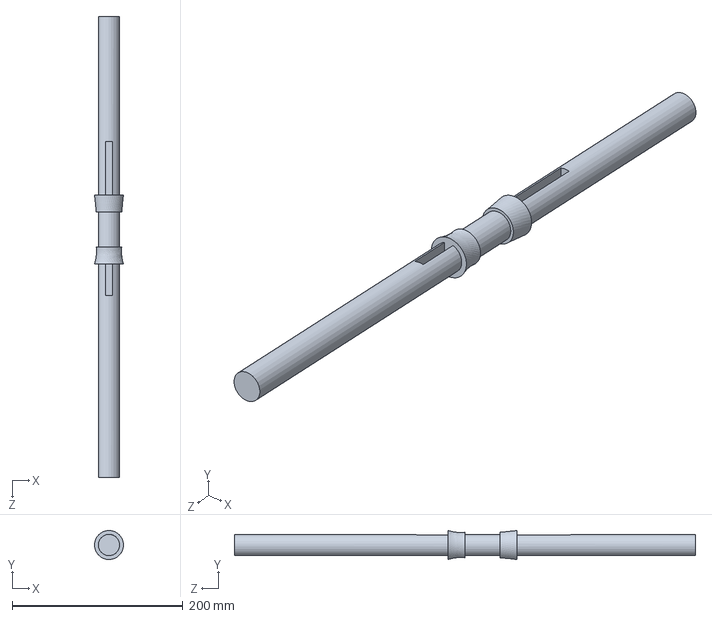
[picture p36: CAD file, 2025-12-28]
CAD/Parts/Shafts/shaft_stage_2.SLDPRT
34.0 x 34.0 x 540.0 mm

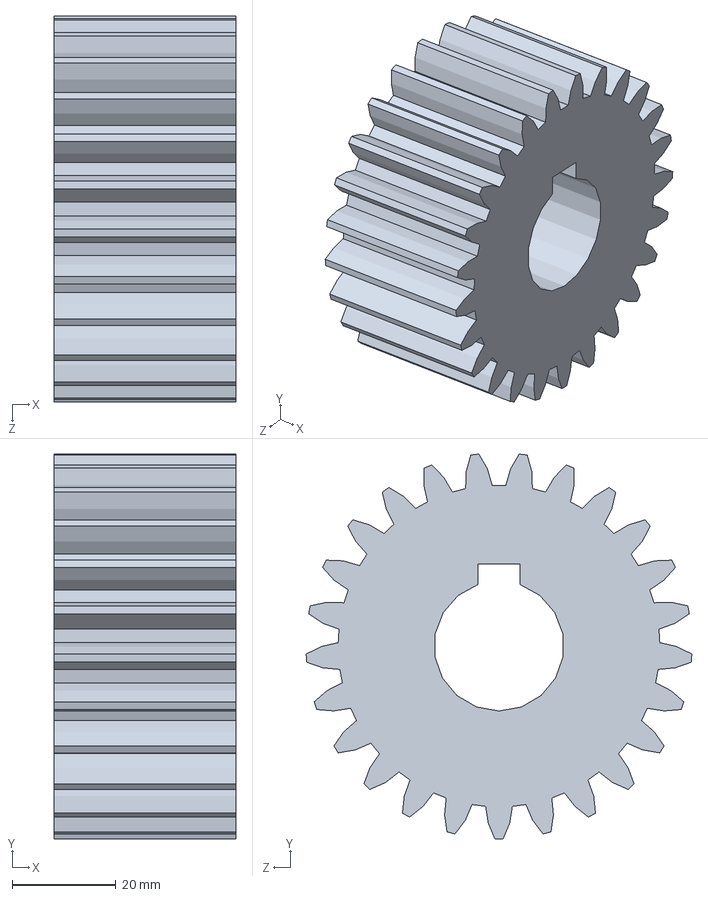
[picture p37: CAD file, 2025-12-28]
CAD/Parts/Gears/gear_stage_2_Spur_driver.SLDPRT
35.0 x 74.0 x 74.2 mm

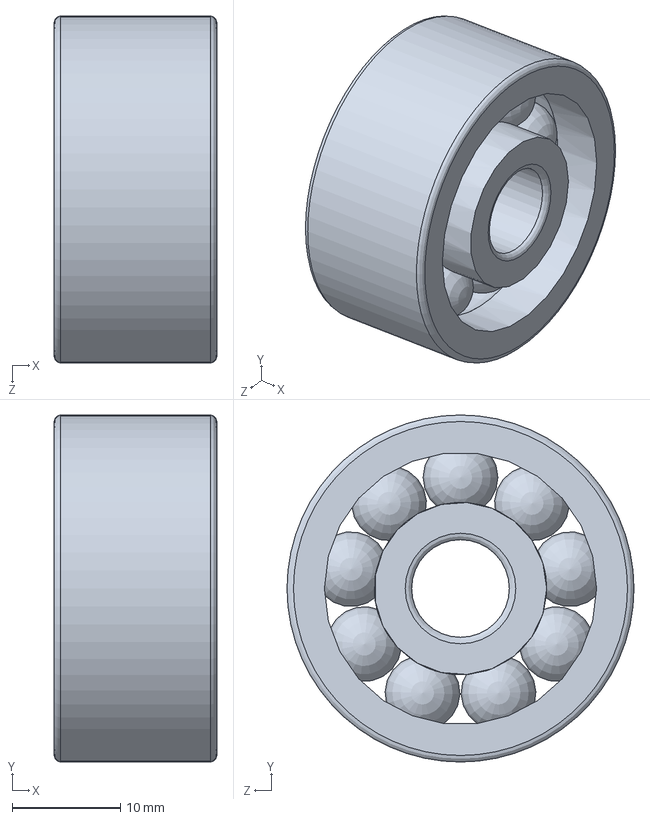
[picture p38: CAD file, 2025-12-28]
CAD/Parts/Key & Bearing/bearings.SLDPRT
15.0 x 32.0 x 32.0 mm

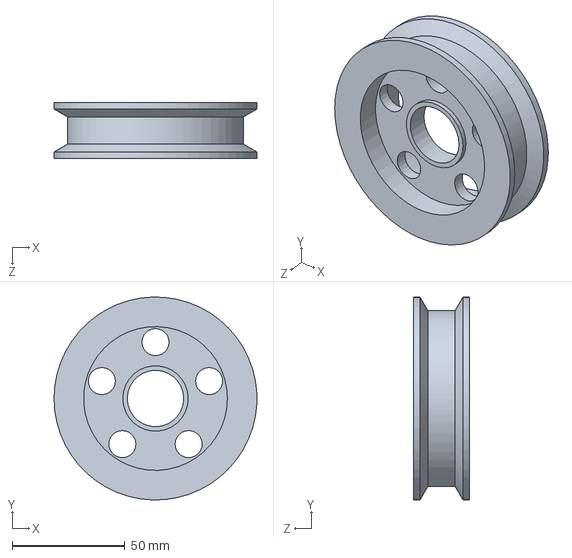
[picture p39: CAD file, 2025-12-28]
CAD/Parts/Power_Transmission/Pulley & Belt/pulley_large.SLDPRT
90.0 x 90.0 x 25.0 mm

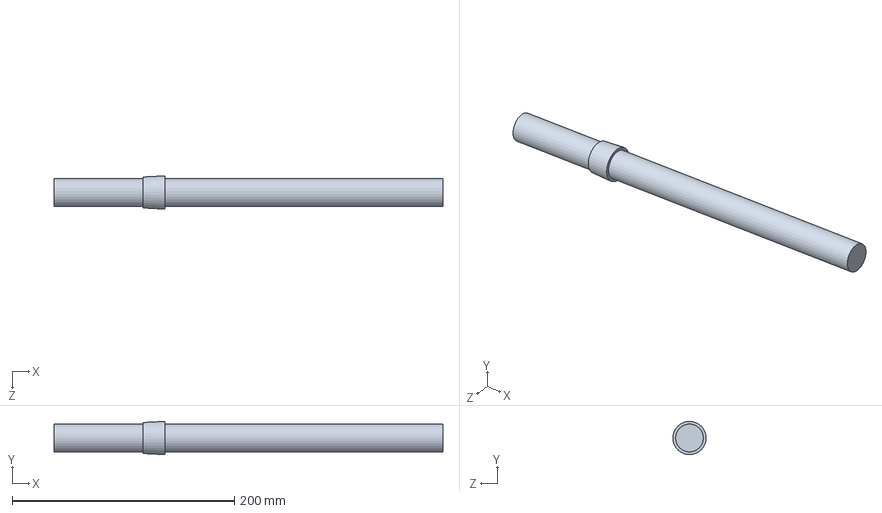
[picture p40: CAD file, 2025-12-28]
CAD/Parts/Shafts/output_shaft_stage_4.SLDPRT
350.0 x 30.0 x 30.0 mm

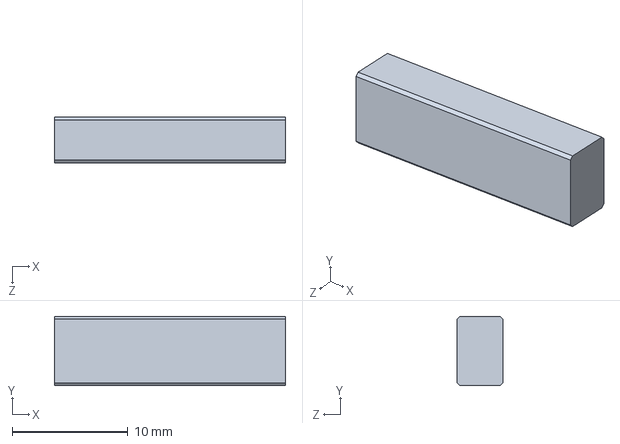
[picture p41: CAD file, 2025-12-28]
CAD/Parts/Key & Bearing/key_d20.SLDPRT
20.0 x 6.00 x 4.00 mm

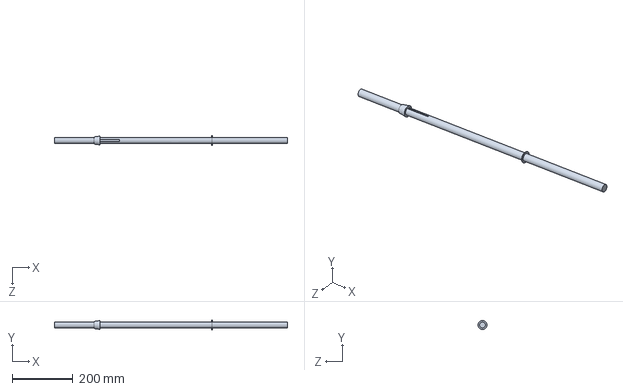
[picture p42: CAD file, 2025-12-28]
CAD/Parts/Shafts/shaft_stage_1.SLDPRT
770.0 x 30.0 x 30.0 mm

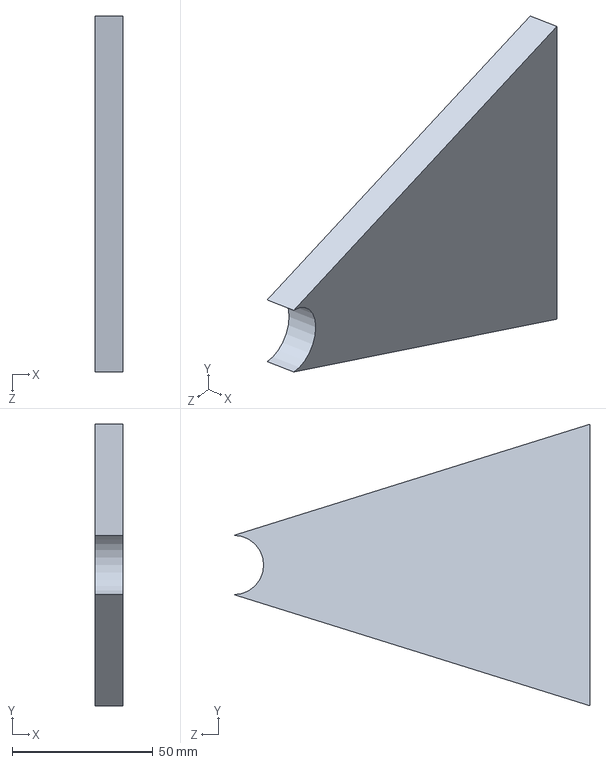
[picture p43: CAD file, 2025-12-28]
CAD/Assemblies/Support_shaft_stage_4.SLDPRT
10.0 x 100.0 x 126.4 mm

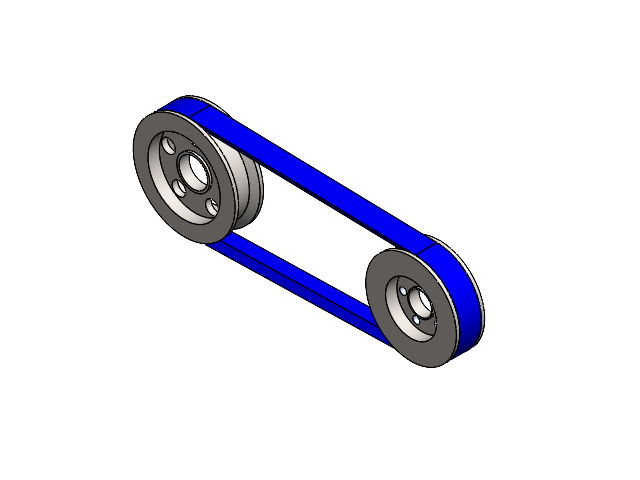
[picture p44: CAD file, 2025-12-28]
CAD/Assemblies/belt_pulley_transmission.SLDASM
big pulley
small pulley
Belt1-5^belt and pulley

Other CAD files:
CAD/Assemblies/full_gearbox_assembly.SLDASM
CAD/Parts/Power_Transmission/Coupling/motor_coupling.SLDPRT
CAD/Parts/Gears/gear_stage_2_Spur_driven.SLDPRT
CAD/Parts/Gears/gear_stage_1_Helical_driver.SLDPRT
CAD/Parts/Shafts/shaft_stage_3.SLDPRT

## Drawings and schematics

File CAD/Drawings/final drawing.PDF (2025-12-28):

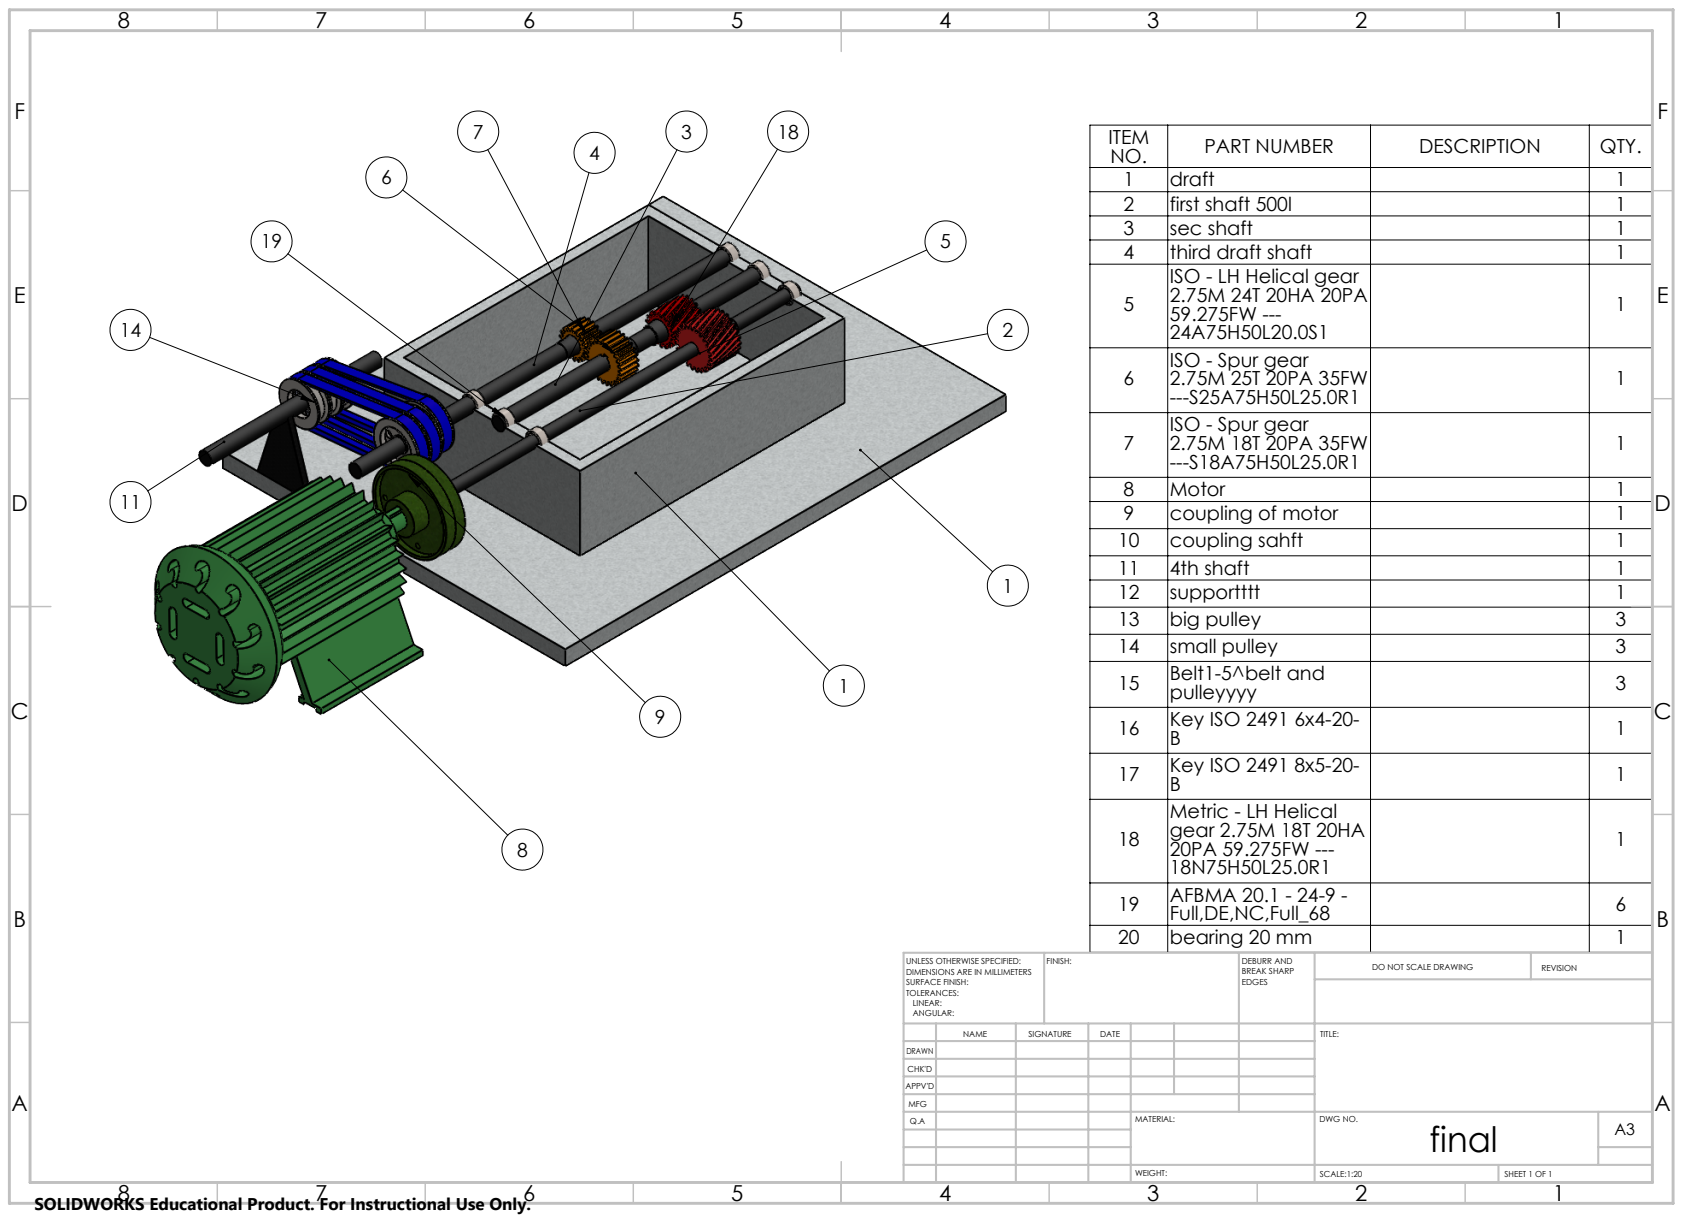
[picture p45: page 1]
first shaft 500l; SCALE:1:20; SHEET 1 OF 1

ITEM NO. | PART NUMBER | DESCRIPTION | QTY.
1 | draft | | 1
3 | sec shaft | | 1
4 | third draft shaft | | 1
5 | ISO - LH Helical gear 2.75M 24T 20HA 20PA 59.275FW ---24A75H50L20.0S1 | | 1

6 | ISO - Spur gear 2.75M 25T 20PA 35FW ---S25A75H50L25.0R1 | | 1

7 | ISO - Spur gear 2.75M 18T 20PA 35FW ---S18A75H50L25.0R1 | | 1

8 | Motor | | 1
9 | coupling of motor | | 1
10 | coupling sahft | | 1
11 | 4th shaft | | 1
12 | supportttt | | 1
13 | big pulley | | 3
14 | small pulley | | 3
15 | Belt1-5^belt and pulleyyyy | | 3
16 | Key ISO 2491 6x4-20-B | | 1
17 | Key ISO 2491 8x5-20-B | | 1
18 | Metric - LH Helical gear 2.75M 18T 20HA 20PA 59.275FW ---18N75H50L25.0R1 | | 1

19 | AFBMA 20.1 - 24-9 -Full,DE,NC,Full_68 | | 6
20 | bearing 20 mm | | 1

UNLESS OTHERWISE SPECIFIED: DIMENSIONS ARE IN MILLIMETERS SURFACE FINISH: TOLERANCES: LINEAR: ANGULAR: | FINISH: | DEBURR AND BREAK SHARP EDGES | DO NOT SCALE DRAWING | REVISION

NAME | SIGNATURE | DATE | | | | TITLE:

DRAWN
CHK'D
APPV'D
MFG
Q.A | | | | MATERIAL: | DWG NO. final | A3

SOLIDWORKS Educational Product. For Instructional Use Only.
